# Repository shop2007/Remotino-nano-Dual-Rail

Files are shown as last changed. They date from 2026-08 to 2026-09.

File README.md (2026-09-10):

# Remotino Nano Dual Rail

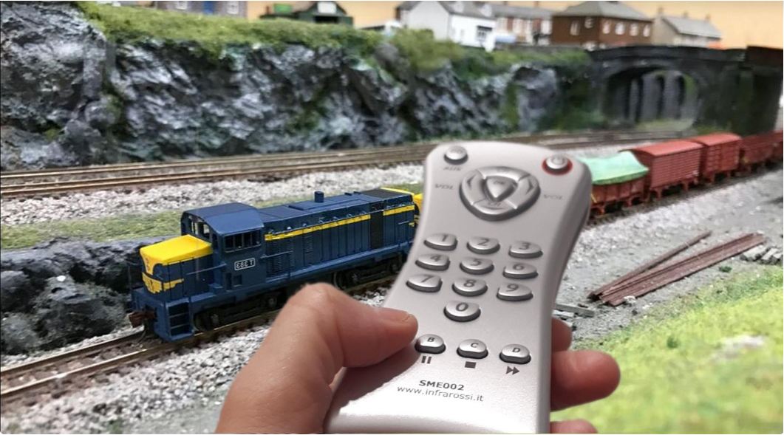
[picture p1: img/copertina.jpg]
Copertina


**Remotino Nano Dual Rail** è l'evoluzione naturale di **Remotino Nano**: un sistema completo per il controllo di un plastico ferroviario, basato su **Arduino Nano**, telecomando a infrarossi e controllo PWM dei due binari.

L'obiettivo del progetto è ottenere un controllo semplice ma preciso dei treni analogici, mantenendo allo stesso tempo la possibilità di gestire scambi, luci e altre utenze del plastico.

---

## 1. Caratteristiche principali

### 1.1 Controllo dei treni

- Controllo di un plastico con **trenini analogici** (tipo LIMA) tramite telecomando a infrarossi.
- **Due binari indipendenti**, controllati in PWM sia per la velocità sia per la direzione.
- Il controllo PWM consente velocità molto basse, realmente in scala, con **partenze e fermate lente e graduali**, più simili al comportamento di un treno reale.

### 1.1.1 Video della bassa velocità
https://github.com/user-attachments/assets/d638dfb1-e052-454d-9ad7-9dd413f32621

### 1.1.2 Video della bassa velocità
<video src="https://github.com/user-attachments/assets/59c75386-90f1-46fd-8587-ddf0c4f8ac02" controls="controls" style="max-width: 100%;"></video>

### 1.2 Gestione di scambi e utenze

- Controllo di **8 relè** per l'attivazione di:
  - scambi;
  - luci;
  - alimentazione di tronchini morti;
  - altre utenze del plastico.
- Se i relè vengono utilizzati per gli scambi in modalità monostabile, sono necessari **2 relè per ogni scambio**.
- Il sistema è espandibile verso schede da **8 o 16 relè con protocollo I²C**.

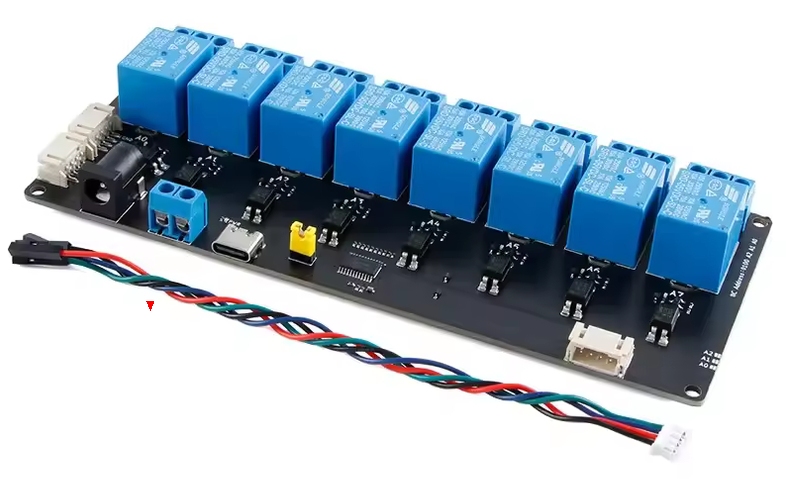
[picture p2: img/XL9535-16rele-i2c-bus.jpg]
Scheda 16 relè con bus I2C


### 1.3 Funzioni speciali

- Possibilità di unire temporaneamente i due circuiti per permettere il passaggio di un treno da un binario all'altro tramite la funzione **JOIN**.
- Funzione **BOOST** per aiutare la partenza di un treno quando viaggia a velocità molto bassa, in salita o con un carico elevato.
- Regolazione fine del comportamento dinamico tramite **5 potenziometri/trimmer**.
- Protezione dei circuiti tramite **quattro fusibili PTC autoripristinanti**.

---

## 2. Mappa comandi del telecomando

Tutte le funzioni del sistema vengono gestite tramite i tasti del telecomando a infrarossi:

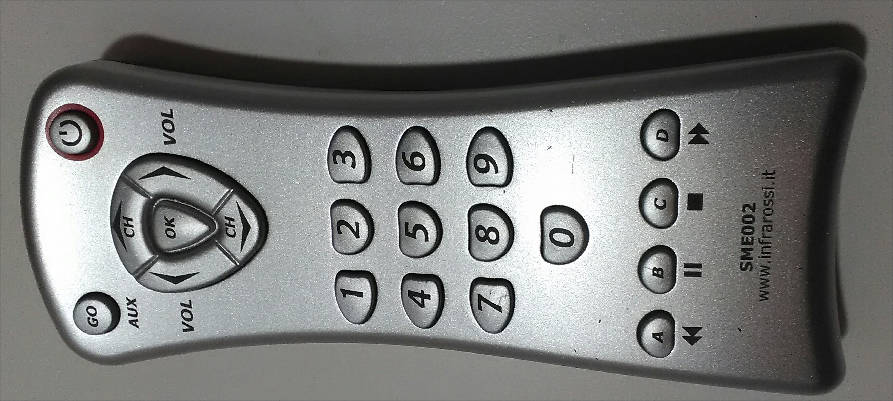
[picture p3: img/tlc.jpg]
Telecomando usato


| Tasto | Funzione / Azione |
| :--- | :--- |
| **GO** | Attiva i motori (*primo tasto da premere per avviare i treni*). |
| **POWER ON** | Ferma immediatamente tutti i treni (Arresto d'emergenza). |
| **CH UP** | Se la potenza è 0 seleziona marcia avanti su **Binario 1** e/o aumenta progressivamente la velocità. Se era selezionata la marcia indietro, riduce la velocità fino ad invertire in marcia avanti. |
| **CH DOWN** | Se la potenza è 0 seleziona marcia indietro su **Binario 1** e/o aumenta progressivamente la velocità. Se era selezionata la marcia avanti, riduce la velocità fino ad invertire in marcia indietro. |
| **VOL +** | Identico a `CH UP`, ma per il **Binario 2**. |
| **VOL -** | Identico a `CH DOWN`, ma per il **Binario 2**. |
| **OK** *(Tasto centrale)* | **Boost** alla massima velocità per il binario selezionato (entrambi se la funzione `JOIN` è attiva). |
| **0** | Porta lentamente la velocità a 0 per il binario selezionato (entrambi se la funzione `JOIN` è attiva). |
| **9** | Attiva la modalità **JOIN** (unione temporanea dei due binari). Si disattiva con **0**|
| **1 – 8** | Aziona il rispettivo relè (da 1 a 8) del banco selezionato, in base alla modalità impostata (chiude temporaneamente in monostabile o inverte lo stato in bistabile). |
| **A** | Seleziona il **Banco 1** di 8 relè (imposta `MODO_A` alla configurazione/reset). |
| **B** | Seleziona il **Banco 2** di 8 relè (imposta `MODO_B` alla configurazione/reset). |
| **C** | Seleziona il **Banco 3** di 8 relè (imposta `MODO_C` alla configurazione/reset). |
| **D** | Seleziona il **Banco 4** di 8 relè (imposta `MODO_D` alla configurazione/reset). |

---

## 3. Architettura del sistema

Il progetto è organizzato attorno ad Arduino Nano, che gestisce:

- i due circuiti di alimentazione dei binari;
- la regolazione PWM della velocità;
- il comando della direzione;
- la funzione JOIN;
- gli 8 relè;
- la ricezione dei comandi dal telecomando;
- la lettura dei potenziometri per la calibrazione della risposta dinamica;
- la comunicazione seriale con il PC.

Per la realizzazione pratica vengono utilizzati, dove possibile, **moduli e schede commerciali**. Lo schema generale riportato più avanti è quindi utile per comprendere l'architettura, mentre per una replica completa del progetto bisogna fare riferimento allo **schema reale KiCad** contenuto nella cartella `kicad`.

---

## 4. Configurazione degli 8 relè

Gli 8 relè possono essere configurati in **quattro modalità**, in funzione dell'utilizzo previsto sul plastico.

| Modalità | Configurazione |
|---|---|
| **MODO_A** | 8 relè monostabili per 4 scambi. Il tasto 1 chiude il relè 1 finché resta premuto. |
| **MODO_B** | 8 relè bistabili ON/OFF per 8 attivazioni. Il tasto 1 inverte lo stato del relè 1 a ogni pressione. |
| **MODO_C** | 6 relè monostabili per 3 scambi + 2 relè bistabili ON/OFF per 2 attivazioni. |
| **MODO_D** | 4 relè monostabili per 2 scambi + 4 relè bistabili ON/OFF per 2 attivazioni. |

### Memorizzazione della modalità

La modalità viene selezionata **subito dopo il reset** premendo il relativo tasto:

- `A` → MODO_A
- `B` → MODO_B
- `C` → MODO_C
- `D` → MODO_D

La configurazione scelta viene quindi **memorizzata nella EEPROM** e mantenuta anche dopo lo spegnimento.

---

## 5. Cambio binario — funzione JOIN

La funzione **JOIN** permette di far passare un treno dal binario 1 al binario 2 evitando il collegamento diretto fra due circuiti che possono trovarsi a tensioni differenti.

### 5.1 Preparazione del collegamento

Per consentire fisicamente il passaggio del treno, i due circuiti devono essere collegati da un tratto di binario che presenti una **interruzione su entrambe le rotaie**.

Nel prototipo questa interruzione è stata realizzata con un seghetto da ferro.

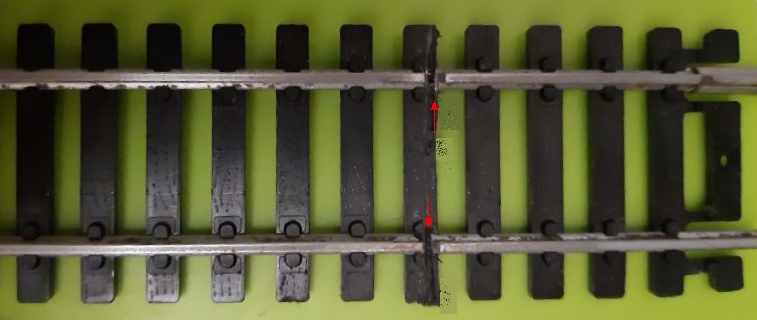
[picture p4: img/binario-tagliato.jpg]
Foto binario tagliato


Non è necessario unire elettricamente i due circuiti: è proprio la funzione JOIN che predispone Arduino a generare due tensioni identiche, permettendo il passaggio da un binario all'altro, senza problema alcuno.

### 5.2 Funzionamento

Premendo il **tasto 9**:

1. le tensioni dei due circuiti vengono portate a zero;
2. viene attivata la modalità JOIN;
3. lo stesso comando viene applicato a entrambi i circuiti;
4. il treno può attraversare il tratto di collegamento passando da un binario all'altro;
5. terminata la necessità del collegamento, il sistema può tornare al normale funzionamento indipendente.

In questo modo il passaggio avviene senza applicare direttamente al treno due tensioni differenti.

### 5.3 Protezione

Quattro **fusibili PTC autoripristinanti** proteggono i circuiti da eventuali errori.

Un esempio particolarmente importante è il tentativo di cambiare binario **senza aver prima attivato la funzione JOIN**: in questa situazione si potrebbe creare un cortocircuito fra circuiti alimentati a tensioni differenti.

---

## 6. Funzione BOOST

La funzione **BOOST** è pensata per i casi in cui il treno, viaggiando alla velocità minima, tende a fermarsi.

Premendo il tasto **OK** del telecomando:

- viene individuato l'ultimo circuito pilotato;
- se il sistema è in modalità JOIN, la funzione può interessare entrambi i circuiti;
- vengono applicati **brevi impulsi alla massima tensione**.

Il BOOST può essere utile:

- alla velocità minima;
- per superare una salita;
- quando il treno ha molti vagoni;
- quando un motore fatica a ripartire.

L'impulso ha lo scopo di **sbloccare il treno e consentirgli di riprendere il movimento**, senza dover aumentare stabilmente la velocità impostata.

---

## 7. Regolazione tramite Potenziometri / Trimmer

Sulla scheda sono presenti **5 potenziometri (o trimmer)** che consentono di personalizzare in modo preciso il comportamento dei treni e le rampe di accelerazione/frenata:

1. **Valore Boost**  
   Regola la durata/intensità dell'impulso di spunto al momento dell'avvio o alla pressione del tasto dedicato (`OK`), permettendo di superare gli attriti meccanici iniziali o i punti critici del plastico.

2. **Valore Minimum Speed**  
   Imposta il livello minimo del segnale PWM (velocità minima). Permette di definire la soglia alla quale la motrice inizia a muoversi senza ronzii o stalli del motore.

3. **Accelerazione**  
   Imposta la pendenza della rampa di accelerazione. Permette di determinare il tempo impiegato dal treno per raggiungere la velocità desiderata, simulando la tipica inerzia delle motrici reali.

4. **Decelerazione**  
   Regola la rampa di decelerazione standard durante le normali variazioni di velocità o cambi di marcia, garantendo rallentamenti morbidi e realistici.

5. **Deceleraz. fermata automatica**  
   Regola la rampa di arresto dedicata alle fermate automatiche (es. alla pressione del tasto `0` . Permette di variare la curva di decelerazione automatica fino all'arresto del treno.

---

## 8. Remotino Display

Collegando Arduino Nano a una porta USB e avviando l'eseguibile **Remotino Display**, è possibile visualizzare sul PC lo stato del sistema.

Il pannello mostra:

- stato di **MOTOR ON**;
- direzione dei due binari;
- stato della funzione **JOIN** (comando 9);
- due VU meter analogici con la potenza erogata ai due motori;
- stato dei **4 scambi**.

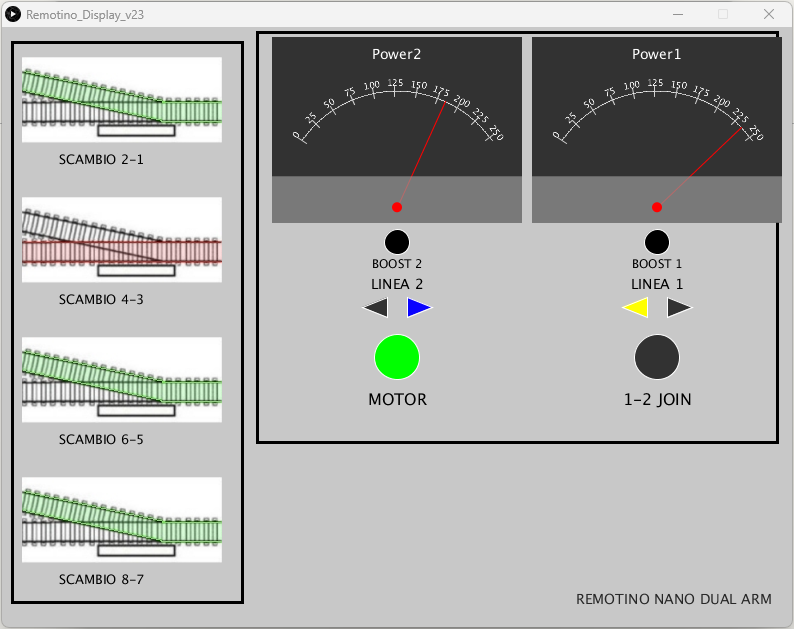
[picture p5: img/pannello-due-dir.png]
Pannello di controllo su PC


Il Remotino Display è quindi particolarmente utile per il controllo e il monitoraggio del plastico durante il funzionamento.

---

## 9. Debug e verifica dell'hardware

In caso di malfunzionamento dell'hardware è possibile utilizzare il **monitor seriale di Arduino** per comandare direttamente i relè e verificarne il funzionamento.

Il formato del comando è:

`rXY`

dove:

- `r` identifica il comando relè;
- `X` identifica il numero del relè;
- `Y` indica lo stato:
  - `1` = ON
  - `0` = OFF

### Esempi

- `r11` → attiva il relè 1
- `r20` → disattiva il relè 2

Questa funzione consente di verificare i relè indipendentemente dal normale funzionamento del telecomando e delle altre funzioni del programma.

---

## 10. Schema generale e realizzazione hardware

### 10.1 Schema generale

Lo schema seguente mostra, a titolo esemplificativo, l'architettura complessiva del sistema (mancano i 5 trimmer/pot.).

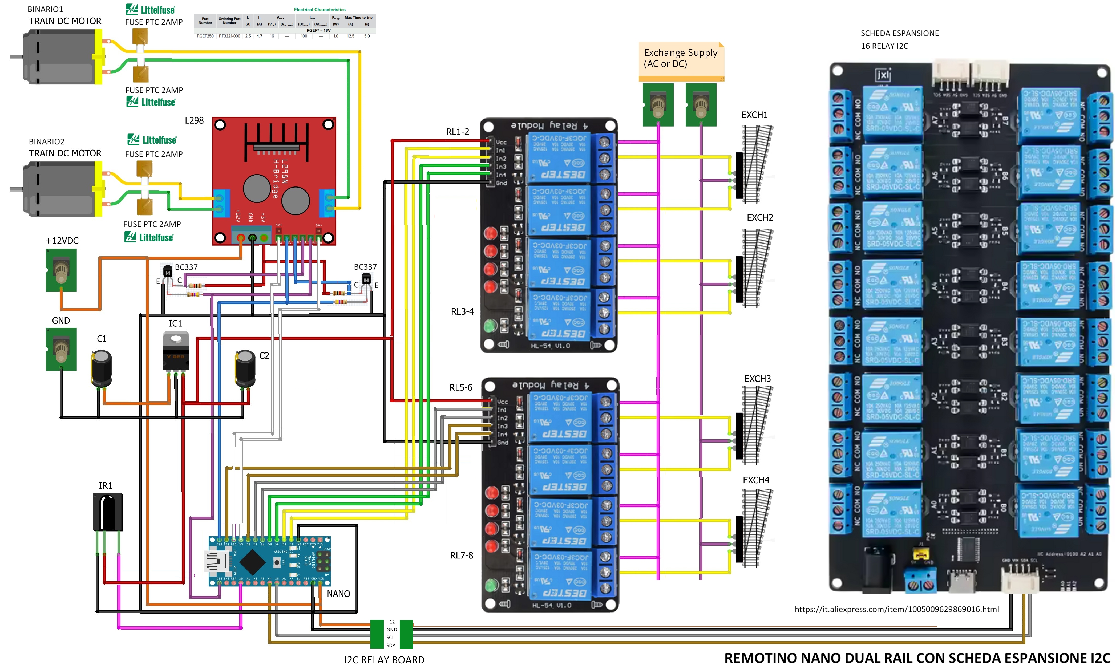
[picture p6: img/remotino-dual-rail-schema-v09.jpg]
Schemone generale


Per **replicare realmente il progetto** fa fede lo schema elettrico completo realizzato in **KiCad**, disponibile nella cartella `kicad`.

Dove possibile sono state impiegate schede e moduli commerciali, in modo da semplificare la costruzione e la reperibilità dei componenti.

### 10.2 PCB

Il PCB è in fase di sviluppo.

Se sei interessato ad averne uno, è possibile prenotarlo: viene fornito **al costo** e nudo (senza componenti).

---

## 11. Prototipo

Questa è l'immagine del primo prototipo, realizzato come verifica preliminare del progetto.

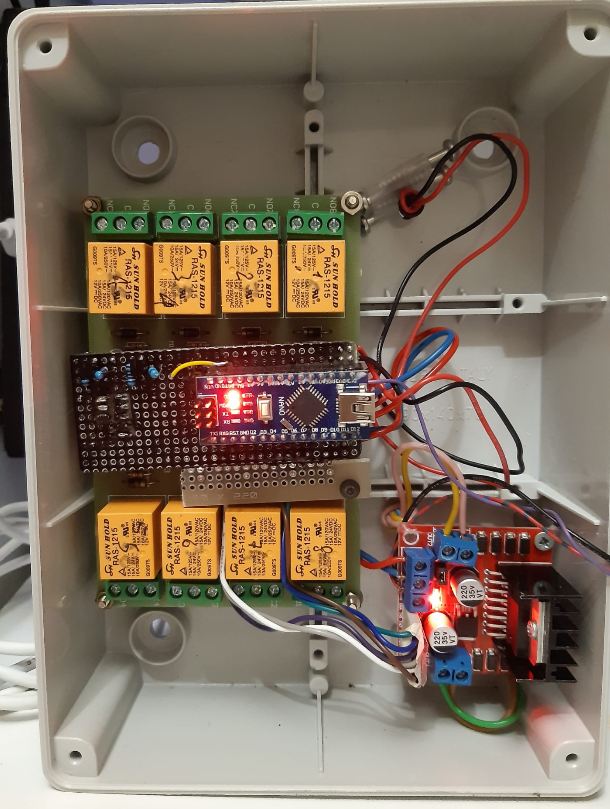
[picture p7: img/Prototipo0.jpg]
Primo prototipo


Il prototipo verrà sostituito da una costruzione più definitiva con il PCB dedicato.

---

## 12. Sorgenti OPEN SOURCE

Tutti i sorgenti del progetto sono disponibili nella cartella **`Sorgenti`**.

Sono disponibili:

- i sorgenti per **Arduino Nano**;
- i sorgenti del programma **Remotino Display**.
- gli schemi **Kicad**.

Il progetto può quindi essere studiato, modificato e adattato alle proprie esigenze.

---

## 13. Istruzioni per la realizzazione

Per chi ha meno esperienza con Arduino è disponibile una guida **passo-passo** nella cartella **`Istruzioni facili`**.

La guida è stata pensata per consentire di replicare il progetto anche a chi possiede solo una conoscenza di base di Arduino e dell'elettronica.

In caso di difficoltà durante la realizzazione, è possibile segnalare il problema per ricevere supporto ( LPAUTAS GMAIL).

---

## 14. In sintesi

**Remotino Nano Dual Rail** riunisce in un unico sistema:

- controllo indipendente di **due treni analogici**;
- regolazione PWM della velocità e della direzione;
- partenze e fermate progressive;
- regolazione personalizzabile di **accelerazione, decelerazione, stop, min speed e boost** tramite 5 trimmer;
- funzione **JOIN** per il passaggio fra i due circuiti;
- funzione **BOOST** per facilitare la partenza dei treni;
- gestione di **8 relè**, configurabili in quattro modalità;
- possibilità di espansione tramite **I²C**;
- protezione tramite PTC autoripristinanti;
- monitoraggio tramite **Remotino Display**;
- funzioni di **debug hardware**;
- sorgenti open source;
- documentazione passo-passo per la realizzazione.



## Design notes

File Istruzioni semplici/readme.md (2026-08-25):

# Checklist realizzazione — Remotino Nano Dual Rail

Guida pratica per chi parte da zero, basata sulle cartelle presenti nella repository.

## Software

1. Scarica e installa **Arduino IDE 2** dal sito ufficiale arduino.cc.
2. Apri Arduino IDE e carica lo sketch `.ino` che trovi nella cartella **"Arduino Sketch"**. Assicurati di aver installato la libreria IRremote v. 2,7,0 di Shirriff (le versioni successive non funzionano con questo progetto).
3. Prova a compilarlo (Verifica). Se l'IDE segnala una libreria mancante, installala dal **Library Manager** (icona libro a sinistra) e ricompila.
4. Collega l'Arduino Nano al PC via USB, seleziona la scheda **"Arduino Nano"** e la porta seriale corretta, poi carica lo sketch sulla scheda. Attenzione, con i cloni è necessario installare il driver USB CH341SER.EXE scaricabile dal sito ufficiale WCH (WCH-IC) .
5. Apri il monitor seriale a 115200 baud e verifica che compaiano i messaggi diagnostici (es. `PWM1=`, `MOTN=`) quando invii un comando relè via seriale (es. `r11`, `r20`).

## Hardware e schema

6. Realizza il circuito che trovi nella cartella  **"img"** per capire l'architettura complessiva del sistema (binari, relè, telecomando, alimentazione).
7. Se hai poca esperienza con Arduino ed elettronica, segui la guida passo-passo nella cartella **"Istruzioni semplici"**.
8. Per la realizzazione elettrica reale (o per farti fare il PCB), apri lo schema completo nella cartella **"Kicad"** — serve installare KiCad se vuoi visualizzarlo o modificarlo.
9. Realizza il cablaggio seguendo lo schema KiCad: alimentazione, i due circuiti binario, le schede relè, i 4 fusibili PTC.
10. Inserisci l'Arduino Nano nello zoccolo/basetta predisposta.
11. Se vuoi usare la funzione **JOIN**, taglia con un seghetto entrambe le rotaie nel punto di collegamento tra binario 1 e binario 2 (senza unirle elettricamente).

## Primo avvio e collaudo

12. Alimenta il sistema e, con il monitor seriale aperto, verifica lo stato generale prima di collegare il telecomando.
13. Alla prima accensione (o dopo un reset), premi subito **A / B / C / D** per scegliere la modalità dei relè (Banco 1‑4: monostabili per scambi, bistabili per luci, o combinazioni miste) — la scelta va fatta entro i primi tasti premuti, poi resta salvata in EEPROM.
14. Prova i comandi da telecomando: premi **GO** per abilitare i motori (nessun treno si muove prima), poi **CH+/CH−** per il binario 1 e **VOL+/VOL−** per il binario 2.
15. Prova **OK** per il boost e **0** per fermare dolcemente il binario selezionato; verifica **POWER ON** come arresto d'emergenza di tutto.
16. Se hai realizzato il taglio del binario, prova la funzione **JOIN** con il tasto **9** e verifica il passaggio del treno tra i due binari, poi disattivala con **0**.
17. Prova i tasti **1–8** per verificare l'attivazione dei relè nella modalità scelta.

## Remotino Display (opzionale ma consigliato)

18. Installa Processing usando il link nella cartella **"Processing installer"** )versioni più aggiornate non compilano il sorgente).
19. Apri lo sketch .pde dentro **"Processing sketch"** e avvialo con l'Arduino collegato via USB, per visualizzare il pannello di stato (Motor On, direzione, JOIN, VU meter di potenza, stato dei 4 scambi). Opzionalmente puoi provare direttamente il file .exe che trovi nella cartella **"Processing sketch\application.windows64"** .. non sempre funziona.

## Se qualcosa non funziona

20. Usa il monitor seriale per comandare i relè manualmente (`rXY`, es. `r11` accende il relè 1, `r20` spegne il relè 2) e isolare se il problema è hardware o software.

## Appendice: elenco parti

- Telecomando: Wallis Universal SME002 (trovato su ebay, vinted) - E' possibile usare qualsiasi telecomando ma serve modificare lo sketch con i codici corretti, e si rischia di ricevere disturbi da telecomandi tv, vcr ecc
- Testina IR: vanno tutte bene, ma consiglio la LTM-8848 LITEON perchè è schermata ed ha una elevata sensibilità (trovata su ebay, vinted)
- Arduino NANO (originale o clone)
- Scheda 4 relè (2 pezzi) ( https://it.aliexpress.com/item/1005008364256415.html )
- Scheda opzionale 8/16 relè I2C bus ( https://it.aliexpress.com/item/1005009629869016.html )
- Scheda PWM L298 ( https://it.aliexpress.com/item/1005012997846403.html )
- BC337
- Resistori e trimmer vari
- Connettori vari
- Fusibili PTC da 2 amp (Littelfuse RUE110 oppure Bourns MF-R110)
- PCB Remotino Nano Dual Rail (in preparazione, prenota il tuo)

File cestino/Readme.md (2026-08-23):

# Remotino Nano Dual Rail

Copertina

**Remotino Nano Dual Rail** è l'evoluzione naturale di **Remotino Nano**: un sistema completo per il controllo di un plastico ferroviario in scala H0, basato su **Arduino Nano**, telecomando a infrarossi e controllo PWM dei due binari.

L'obiettivo del progetto è ottenere un controllo semplice ma preciso dei treni analogici, mantenendo allo stesso tempo la possibilità di gestire scambi, luci e altre utenze del plastico.

---

## 1. Caratteristiche principali

### 1.1 Controllo dei treni

- Controllo di un plastico con **trenini analogici** (tipo LIMA) tramite telecomando a infrarossi.

Telecomando usato

- **Due binari indipendenti**, controllati in PWM sia per la velocità sia per la direzione.
- Il controllo PWM consente velocità molto basse, realmente in scala 1:87, con **partenze e fermate lente e graduali**, più simili al comportamento di un treno reale.

https://github.com/user-attachments/assets/d638dfb1-e052-454d-9ad7-9dd413f32621

### 1.2 Gestione di scambi e utenze

- Controllo di **8 relè** per l'attivazione di:
  - scambi;
  - luci;
  - alimentazione di tronchini morti;
  - altre utenze del plastico.
- Se i relè vengono utilizzati per gli scambi in modalità monostabile, sono necessari **2 relè per ogni scambio**.
- Il sistema è espandibile verso schede da **8 o 16 relè con protocollo I²C**.

Scheda 16 relè con bus I2C

### 1.3 Funzioni speciali

- Possibilità di unire temporaneamente i due circuiti per permettere il passaggio di un treno da un binario all'altro tramite la funzione **JOIN**.
- Funzione **BOOST** per aiutare la partenza di un treno quando viaggia a velocità molto bassa, in salita o con un carico elevato.
- Protezione dei circuiti tramite **quattro fusibili PTC autoripristinanti**.

---

## 2. Architettura del sistema

Il progetto è organizzato attorno ad Arduino Nano, che gestisce:

- i due circuiti di alimentazione dei binari;
- la regolazione PWM della velocità;
- il comando della direzione;
- la funzione JOIN;
- gli 8 relè;
- la ricezione dei comandi dal telecomando;
- la comunicazione seriale con il PC.

Per la realizzazione pratica vengono utilizzati, dove possibile, **moduli e schede commerciali**. Lo schema generale riportato più avanti è quindi utile per comprendere l'architettura, mentre per una replica completa del progetto bisogna fare riferimento allo **schema reale KiCad** contenuto nella cartella `kicad`.

---

## 3. Configurazione degli 8 relè

Gli 8 relè possono essere configurati in **quattro modalità**, in funzione dell'utilizzo previsto sul plastico.

| Modalità | Configurazione |
|---|---|
| **MODO_A** | 8 relè monostabili per 4 scambi. Il tasto 1 chiude il relè 1 finché resta premuto. |
| **MODO_B** | 8 relè bistabili ON/OFF per 8 attivazioni. Il tasto 1 inverte lo stato del relè 1 a ogni pressione. |
| **MODO_C** | 6 relè monostabili per 3 scambi + 2 relè bistabili ON/OFF per 2 attivazioni. |
| **MODO_D** | 4 relè monostabili per 2 scambi + 4 relè bistabili ON/OFF per 2 attivazioni. |

### Memorizzazione della modalità

<<<<<<< HEAD
La modalità viene selezionata **subito dopo il reset** premendo il relativo tasto:
=======
Per passare dal binario 1 al binario 2 è necessario che i due circuiti siano uniti da un binario con una interruzione su entramble le rotaie (io l'ho fatto con un segheto da ferro); per il passaggio non serve unirle elettricamente, perché attivando la modalità "join" con il tasto 9, le tensioni dei due circuiti vengono prima azzerate e poi viene applicato lo stesso comando su entrambi i circuiti, permettendo al treno di passare da un binario all'altro in modo del tutto indolore.
Foto binario tagliato
>>>>>>> 6fffbd93348ce626d40769e0fa216ff54d8fa7e9

- `A` → MODO_A
- `B` → MODO_B
- `C` → MODO_C
- `D` → MODO_D

La configurazione scelta viene quindi **memorizzata nella EEPROM** e mantenuta anche dopo lo spegnimento.

---

## 4. Cambio binario — funzione JOIN

La funzione **JOIN** permette di far passare un treno dal binario 1 al binario 2 evitando il collegamento diretto fra due circuiti che possono trovarsi a tensioni differenti.

### 4.1 Preparazione del collegamento

Per consentire fisicamente il passaggio del treno, i due circuiti devono essere collegati da un tratto di binario che presenti una **interruzione su entrambe le rotaie**.

Nel prototipo questa interruzione è stata realizzata con un seghetto da ferro.

Foto binario tagliato

Non è necessario unire elettricamente i due circuiti: è proprio la funzione JOIN a gestire temporaneamente le loro tensioni.

### 4.2 Funzionamento

Premendo il **tasto 9**:

1. le tensioni dei due circuiti vengono portate a zero;
2. viene attivata la modalità JOIN;
3. lo stesso comando viene applicato a entrambi i circuiti;
4. il treno può attraversare il tratto di collegamento passando da un binario all'altro;
5. terminata la necessità del collegamento, il sistema può tornare al normale funzionamento indipendente.

In questo modo il passaggio avviene senza applicare direttamente al treno due tensioni differenti.

### 4.3 Protezione

Quattro **fusibili PTC autoripristinanti** proteggono i circuiti da eventuali errori.

Un esempio particolarmente importante è il tentativo di cambiare binario **senza aver prima attivato la funzione JOIN**: in questa situazione si potrebbe creare un cortocircuito fra circuiti alimentati a tensioni differenti.

---

## 5. Funzione BOOST

La funzione **BOOST** è pensata per i casi in cui il treno, viaggiando alla velocità minima, tende a fermarsi.

Premendo il tasto **OK** del telecomando:

- viene individuato l'ultimo circuito pilotato;
- se il sistema è in modalità JOIN, la funzione può interessare entrambi i circuiti;
- vengono applicati **brevi impulsi alla massima tensione**.

Il BOOST può essere utile:

- alla velocità minima;
- per superare una salita;
- quando il treno ha molti vagoni;
- quando un motore fatica a ripartire.

L'impulso ha lo scopo di **sbloccare il treno e consentirgli di riprendere il movimento**, senza dover aumentare stabilmente la velocità impostata.

---

## 6. Remotino Display

Collegando Arduino Nano a una porta USB e avviando l'eseguibile **Remotino Display**, è possibile visualizzare sul PC lo stato del sistema.

Il pannello mostra:

- stato di **MOTOR ON**;
- direzione dei due binari;
- stato della funzione **JOIN** (comando 9);
- due VU meter analogici con la potenza erogata ai due motori;
- stato dei **4 scambi**.

Pannello di controllo su PC

Il Remotino Display è quindi particolarmente utile per il controllo e il monitoraggio del plastico durante il funzionamento.

---

## 7. Debug e verifica dell'hardware

In caso di malfunzionamento dell'hardware è possibile utilizzare il **monitor seriale di Arduino** per comandare direttamente i relè e verificarne il funzionamento.

Il formato del comando è:

`rXY`

dove:

- `r` identifica il comando relè;
- `X` identifica il numero del relè;
- `Y` indica lo stato:
  - `1` = ON
  - `0` = OFF

### Esempi

- `r11` → attiva il relè 1
- `r20` → disattiva il relè 2

Questa funzione consente di verificare i relè indipendentemente dal normale funzionamento del telecomando e delle altre funzioni del programma.

---

## 8. Schema generale e realizzazione hardware

### 8.1 Schema generale

Lo schema seguente mostra, a titolo esemplificativo, l'architettura complessiva del sistema.

Schemone generale

Per **replicare realmente il progetto** fa fede lo schema elettrico completo realizzato in **KiCad**, disponibile nella cartella `kicad`.

Dove possibile sono state impiegate schede e moduli commerciali, in modo da semplificare la costruzione e la reperibilità dei componenti.

### 8.2 PCB

Il PCB è in fase di costruzione.

Se sei interessato a realizzarne uno, è possibile prenotarlo: viene fornito **al costo**.

---

## 9. Prototipo

Questa è l'immagine del primo prototipo, realizzato come verifica preliminare del progetto.

Primo prototipo

Il prototipo verrà sostituito da una costruzione più definitiva con il PCB dedicato.

---

## 10. Sorgenti OPEN SOURCE

Tutti i sorgenti del progetto sono disponibili nella cartella **`Sorgenti`**.

Sono disponibili:

- i sorgenti per **Arduino Nano**;
- i sorgenti del programma **Remotino Display**.

Il progetto può quindi essere studiato, modificato e adattato alle proprie esigenze.

---

## 11. Istruzioni per la realizzazione

Per chi ha meno esperienza con Arduino è disponibile una guida **passo-passo** nella cartella **`Istruzioni facili`**.

La guida è stata pensata per consentire di replicare il progetto anche a chi possiede solo una conoscenza di base di Arduino e dell'elettronica.

In caso di difficoltà durante la realizzazione, è possibile segnalare il problema per ricevere supporto.

---

## 12. In sintesi

**Remotino Nano Dual Rail** riunisce in un unico sistema:

- controllo indipendente di **due treni analogici**;
- regolazione PWM della velocità e della direzione;
- partenze e fermate progressive;
- funzione **JOIN** per il passaggio fra i due circuiti;
- funzione **BOOST** per facilitare la partenza dei treni;
- gestione di **8 relè**, configurabili in quattro modalità;
- possibilità di espansione tramite **I²C**;
- protezione tramite PTC autoripristinanti;
- monitoraggio tramite **Remotino Display**;
- funzioni di **debug hardware**;
- sorgenti open source;
- documentazione passo-passo per la realizzazione.

<<<<<<< HEAD
=======
## Prototipo
Questa è l'immagine del primi prototipo, in attesa di una costruzione più seria quando ci sarà il pcb.
Prototipo 0

## versioni

# Remotino Nano Dual Rail

Copertina

**Remotino Nano Dual Rail** è l'evoluzione naturale di **Remotino Nano**: un sistema completo per il controllo di un plastico ferroviario in scala H0, basato su **Arduino Nano**, telecomando a infrarossi e controllo PWM dei due binari.

L'obiettivo del progetto è ottenere un controllo semplice ma preciso dei treni analogici, mantenendo allo stesso tempo la possibilità di gestire scambi, luci e altre utenze del plastico.

---

## 1. Caratteristiche principali

### 1.1 Controllo dei treni

- Controllo di un plastico con **trenini analogici** (tipo LIMA) tramite telecomando a infrarossi.

Telecomando usato

- **Due binari indipendenti**, controllati in PWM sia per la velocità sia per la direzione.
- Il controllo PWM consente velocità molto basse, realmente in scala 1:87, con **partenze e fermate lente e graduali**, più simili al comportamento di un treno reale.

https://github.com/user-attachments/assets/d638dfb1-e052-454d-9ad7-9dd413f32621

### 1.2 Gestione di scambi e utenze

- Controllo di **8 relè** per l'attivazione di:
  - scambi;
  - luci;
  - alimentazione di tronchini morti;
  - altre utenze del plastico.
- Se i relè vengono utilizzati per gli scambi in modalità monostabile, sono necessari **2 relè per ogni scambio**.
- Il sistema è espandibile verso schede da **8 o 16 relè con protocollo I²C**.

Scheda 16 relè con bus I2C

### 1.3 Funzioni speciali

- Possibilità di unire temporaneamente i due circuiti per permettere il passaggio di un treno da un binario all'altro tramite la funzione **JOIN**.
- Funzione **BOOST** per aiutare la partenza di un treno quando viaggia a velocità molto bassa, in salita o con un carico elevato.
- Protezione dei circuiti tramite **quattro fusibili PTC autoripristinanti**.

---

## 2. Architettura del sistema

Il progetto è organizzato attorno ad Arduino Nano, che gestisce:

- i due circuiti di alimentazione dei binari;
- la regolazione PWM della velocità;
- il comando della direzione;
- la funzione JOIN;
- gli 8 relè;
- la ricezione dei comandi dal telecomando;
- la comunicazione seriale con il PC.

Per la realizzazione pratica vengono utilizzati, dove possibile, **moduli e schede commerciali**. Lo schema generale riportato più avanti è quindi utile per comprendere l'architettura, mentre per una replica completa del progetto bisogna fare riferimento allo **schema reale KiCad** contenuto nella cartella `kicad`.

---

## 3. Configurazione degli 8 relè

Gli 8 relè possono essere configurati in **quattro modalità**, in funzione dell'utilizzo previsto sul plastico.

| Modalità | Configurazione |
|---|---|
| **MODO_A** | 8 relè monostabili per 4 scambi. Il tasto 1 chiude il relè 1 finché resta premuto. |
| **MODO_B** | 8 relè bistabili ON/OFF per 8 attivazioni. Il tasto 1 inverte lo stato del relè 1 a ogni pressione. |
| **MODO_C** | 6 relè monostabili per 3 scambi + 2 relè bistabili ON/OFF per 2 attivazioni. |
| **MODO_D** | 4 relè monostabili per 2 scambi + 4 relè bistabili ON/OFF per 2 attivazioni. |

### Memorizzazione della modalità

La modalità viene selezionata **subito dopo il reset** premendo il relativo tasto:

- `A` → MODO_A
- `B` → MODO_B
- `C` → MODO_C
- `D` → MODO_D

La configurazione scelta viene quindi **memorizzata nella EEPROM** e mantenuta anche dopo lo spegnimento.

---

## 4. Cambio binario — funzione JOIN

La funzione **JOIN** permette di far passare un treno dal binario 1 al binario 2 evitando il collegamento diretto fra due circuiti che possono trovarsi a tensioni differenti.

### 4.1 Preparazione del collegamento

Per consentire fisicamente il passaggio del treno, i due circuiti devono essere collegati da un tratto di binario che presenti una **interruzione su entrambe le rotaie**.

Nel prototipo questa interruzione è stata realizzata con un seghetto da ferro.

Foto binario tagliato

Non è necessario unire elettricamente i due circuiti: è proprio la funzione JOIN a gestire temporaneamente le loro tensioni.

### 4.2 Funzionamento

Premendo il **tasto 9**:

1. le tensioni dei due circuiti vengono portate a zero;
2. viene attivata la modalità JOIN;
3. lo stesso comando viene applicato a entrambi i circuiti;
4. il treno può attraversare il tratto di collegamento passando da un binario all'altro;
5. terminata la necessità del collegamento, il sistema può tornare al normale funzionamento indipendente.

In questo modo il passaggio avviene senza applicare direttamente al treno due tensioni differenti.

### 4.3 Protezione

Quattro **fusibili PTC autoripristinanti** proteggono i circuiti da eventuali errori.

Un esempio particolarmente importante è il tentativo di cambiare binario **senza aver prima attivato la funzione JOIN**: in questa situazione si potrebbe creare un cortocircuito fra circuiti alimentati a tensioni differenti.

---

## 5. Funzione BOOST

La funzione **BOOST** è pensata per i casi in cui il treno, viaggiando alla velocità minima, tende a fermarsi.

Premendo il tasto **OK** del telecomando:

- viene individuato l'ultimo circuito pilotato;
- se il sistema è in modalità JOIN, la funzione può interessare entrambi i circuiti;
- vengono applicati **brevi impulsi alla massima tensione**.

Il BOOST può essere utile:

- alla velocità minima;
- per superare una salita;
- quando il treno ha molti vagoni;
- quando un motore fatica a ripartire.

L'impulso ha lo scopo di **sbloccare il treno e consentirgli di riprendere il movimento**, senza dover aumentare stabilmente la velocità impostata.

---

## 6. Remotino Display

Collegando Arduino Nano a una porta USB e avviando l'eseguibile **Remotino Display**, è possibile visualizzare sul PC lo stato del sistema.

Il pannello mostra:

- stato di **MOTOR ON**;
- direzione dei due binari;
- stato della funzione **JOIN** (comando 9);
- due VU meter analogici con la potenza erogata ai due motori;
- stato dei **4 scambi**.

Pannello di controllo su PC

Il Remotino Display è quindi particolarmente utile per il controllo e il monitoraggio del plastico durante il funzionamento.

---

## 7. Debug e verifica dell'hardware

In caso di malfunzionamento dell'hardware è possibile utilizzare il **monitor seriale di Arduino** per comandare direttamente i relè e verificarne il funzionamento.

Il formato del comando è:

`rXY`

dove:

- `r` identifica il comando relè;
- `X` identifica il numero del relè;
- `Y` indica lo stato:
  - `1` = ON
  - `0` = OFF

### Esempi

- `r11` → attiva il relè 1
- `r20` → disattiva il relè 2

Questa funzione consente di verificare i relè indipendentemente dal normale funzionamento del telecomando e delle altre funzioni del programma.

---

## 8. Schema generale e realizzazione hardware

### 8.1 Schema generale

Lo schema seguente mostra, a titolo esemplificativo, l'architettura complessiva del sistema.

Schemone generale

Per **replicare realmente il progetto** fa fede lo schema elettrico completo realizzato in **KiCad**, disponibile nella cartella `kicad`.

Dove possibile sono state impiegate schede e moduli commerciali, in modo da semplificare la costruzione e la reperibilità dei componenti.

### 8.2 PCB

Il PCB è in fase di costruzione.

Se sei interessato a realizzarne uno, è possibile prenotarlo: viene fornito **al costo**.

---

## 9. Prototipo

Questa è l'immagine del primo prototipo, realizzato come verifica preliminare del progetto.

Primo prototipo

Il prototipo verrà sostituito da una costruzione più definitiva con il PCB dedicato.

---

## 10. Sorgenti OPEN SOURCE

Tutti i sorgenti del progetto sono disponibili nella cartella **`Sorgenti`**.

Sono disponibili:

- i sorgenti per **Arduino Nano**;
- i sorgenti del programma **Remotino Display**.

Il progetto può quindi essere studiato, modificato e adattato alle proprie esigenze.

---

## 11. Istruzioni per la realizzazione

Per chi ha meno esperienza con Arduino è disponibile una guida **passo-passo** nella cartella **`Istruzioni facili`**.

La guida è stata pensata per consentire di replicare il progetto anche a chi possiede solo una conoscenza di base di Arduino e dell'elettronica.

In caso di difficoltà durante la realizzazione, è possibile segnalare il problema per ricevere supporto.

---

## 12. In sintesi

**Remotino Nano Dual Rail** riunisce in un unico sistema:

- controllo indipendente di **due treni analogici**;
- regolazione PWM della velocità e della direzione;
- partenze e fermate progressive;
- funzione **JOIN** per il passaggio fra i due circuiti;
- funzione **BOOST** per facilitare la partenza dei treni;
- gestione di **8 relè**, configurabili in quattro modalità;
- possibilità di espansione tramite **I²C**;
- protezione tramite PTC autoripristinanti;
- monitoraggio tramite **Remotino Display**;
- funzioni di **debug hardware**;
- sorgenti open source;
- documentazione passo-passo per la realizzazione.

>>>>>>> 6fffbd93348ce626d40769e0fa216ff54d8fa7e9

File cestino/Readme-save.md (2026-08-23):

# Remotino Nano Dual Rail

Copertina

**Remotino Nano Dual Rail** è l'evoluzione naturale di Remotino Nano.

## Caratteristiche principali

- Controllo totale di un plastico con Trenini analogici (tipo LIMA), tramite telecomando a infrarossi

Telecomando usato
  
- Due binari indipendenti, controllati in PWM sia per velocità che per direzione
- Il controllo PWM consente velocità bassissime, realmente in scala 1:87, con partenze e fermate lente e graduali, proprio come un treno vero
 
https://github.com/user-attachments/assets/d638dfb1-e052-454d-9ad7-9dd413f32621

- Possibilità di unire temporaneamente i due circuiti per far passare un treno da un binario all'altro (funzione speciale join tasto 9)
- Controllo di 8 relè per l'attivazione di scambi, luci o alimentazione di tronchini morti. Se usati per gli scambi, in modalità monostabile servono 2 relè per ogni scambio
- Espandibilità verso schede da 8/16 relais con protocollo I2C

Scheda 16 Relè IC bus Aliexp

## Modalità di configurazione degli 8 relè

Gli 8 relè possono essere configurati in 4 modalità:

| Modalità | Configurazione |
|---|---|
| **MODO_A** | 8 relè monostabili per 4 scambi (il tasto 1 chiude il relè 1 finché resta premuto) |
| **MODO_B** | 8 relè bistabili ON/OFF per 8 attivazioni (il tasto 1 inverte lo stato del relè 1 ad ogni pressione) |
| **MODO_C** | 6 relè monostabili per 3 scambi + 2 relè bistabili ON/OFF per 2 attivazioni |
| **MODO_D** | 4 relè monostabili per 2 scambi + 4 relè bistabili ON/OFF per 2 attivazioni |
Questa programmazione va fatta premendo i tasti A,B,C o D appena resettato, poi resta memorizzato nella EEPROM

## Cambio binario (funzione JOIN)

Per passare dal binario 1 al binario 2 è necessario che i due circuiti siano uniti da un binario con una interruzione su entramble le rotaie (io l'ho fatto con un seghetto da ferro); per il passaggio non serve unirle elettricamente, perché attivando la modalità "join" con il tasto 9, le tensioni dei due circuiti vengono prima azzerate e poi viene applicato lo stesso comando su entrambi i circuiti, permettendo al treno di passare da un binario all'altro in modo del tutto indolore.
Foto binario tagliato

Quattro fusibili PTC autoripristinanti proteggono i circuiti da eventuali errori, come ad esempio il tentativo di cambiare binario senza aver prima premuto il tasto 9 — situazione che provocherebbe un cortocircuito tra le diverse tensioni.

## Remotino Display

Collegando Arduino Nano a una porta USB e lanciando l'eseguibile **Remotino Display**, è possibile visualizzare:

- Stato di motor on
- Direzione dei due binari
- Stato di JOIN (comando 9)
- Due VU meter analogici con la potenza erogata ai due motori
- Stato dei 4 scambi
Pannello di controllo su PC

## Debug hardware

In caso di malfunzionamento dell'hardware è possibile inviare alcuni comandi da monitor seriale per attivare i relais e verificarne il funzionamento 

-  r=relay , 1=rl1, 1=on 0=off
- r11 attiva rele1
- r20 disattiva rele 2

## Schema Generale per replicare il progetto
Solo a titolo esemplificativo questo è lo schemone totale del controllo. Dove possibile vengono impegate schede o moduli commerciali. Per replicare il progetto fa fede lo schema reale, fatto in kicad (cartella kicad).
Il PCB è in fase di costruzione, se sei interessato prenotane uno (viene dato "al costo").
Schemone generale

## Tasto BOOST
Sul telecomando premendo il tasto OK si attiva la funzione BOOST: all'ultimo circuito pilotato (o entrambi se siamo in modo JOIN) vengono dati brevi impulsi alla massima tensione: serve per quando abbiamo la velocità al minimo, ed il treno si ferma , o per una salita, o per problemi di carico elevato (numero di vagoni); questo dovrebbe sbloccare il treno e consentirgli di proseguire.

## Sorgenti OPEN SOURCE
Tutti i sorgenti per Arduino Nano e quelli per il "Remotino Display" sono open source disponibili nella cartella "Sorgenti".

## Istruzioni facili per i meno esperti
Ho scritto una istruzione fatta passo-per-passo, che dovrebbe consentire di replicare il progetto a chiunque abbia un minimo di dimestichezza con Arduino. Scrivimi se incontri difficoltà. Cerca la cartella "Istruzioni facili".

## Prototipo
Questa è l'immagine del primi prototipo, in attesa di una costruzione più seria quando ci sarà il pcb.
Prototipo 0

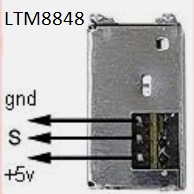
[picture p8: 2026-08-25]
img/LTM8848-PINOUT.jpg

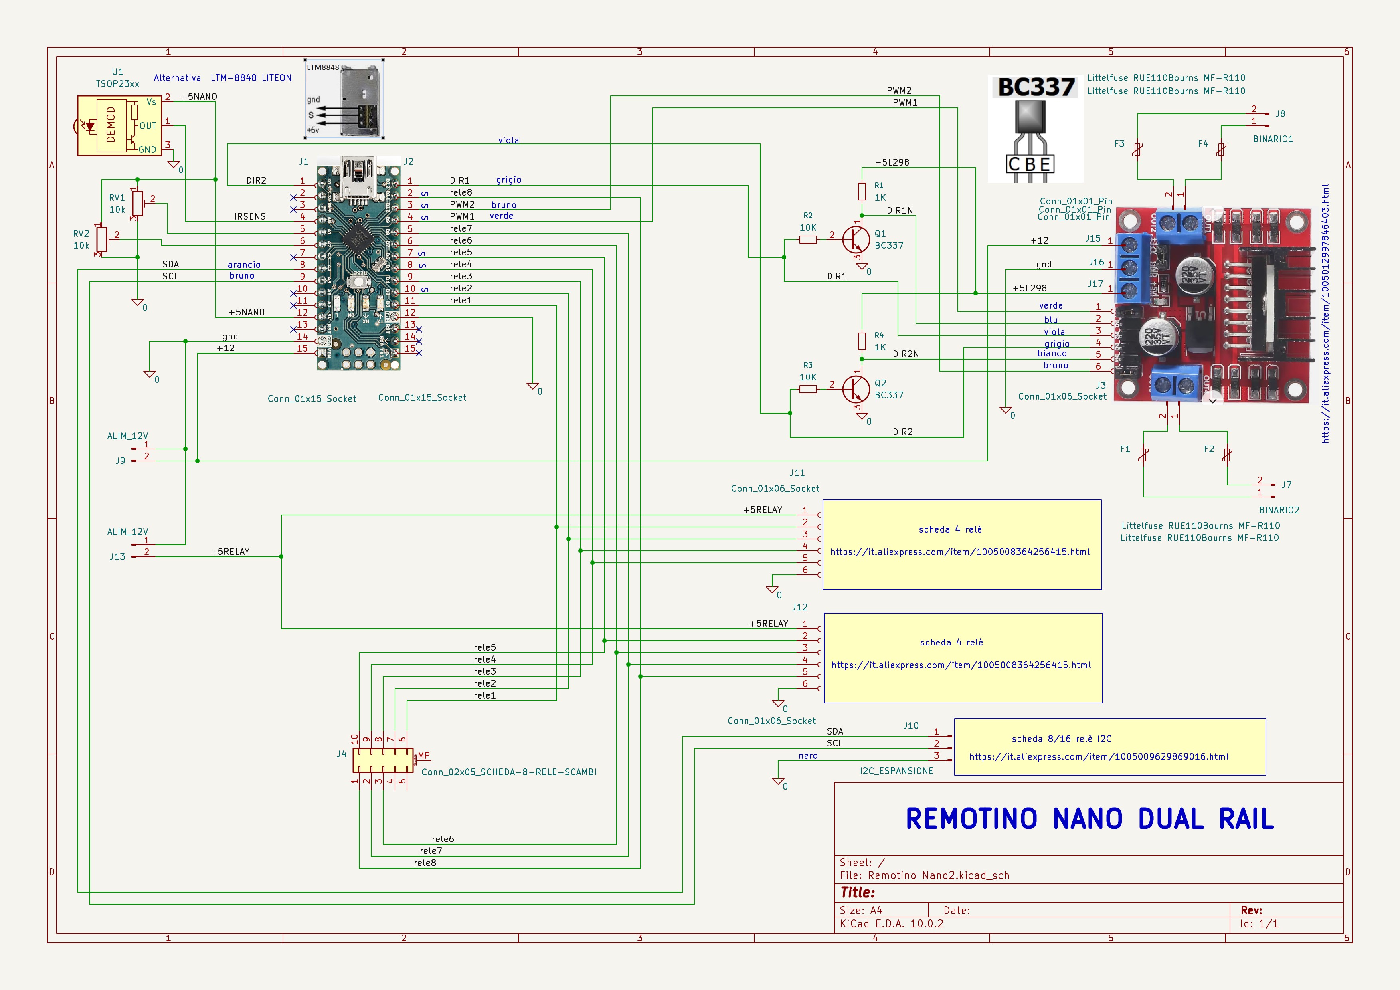
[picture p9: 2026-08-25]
Kicad/Remotino Nano Dual Rail/Schematic Remotino Nano Dual Rail v2.0.jpg

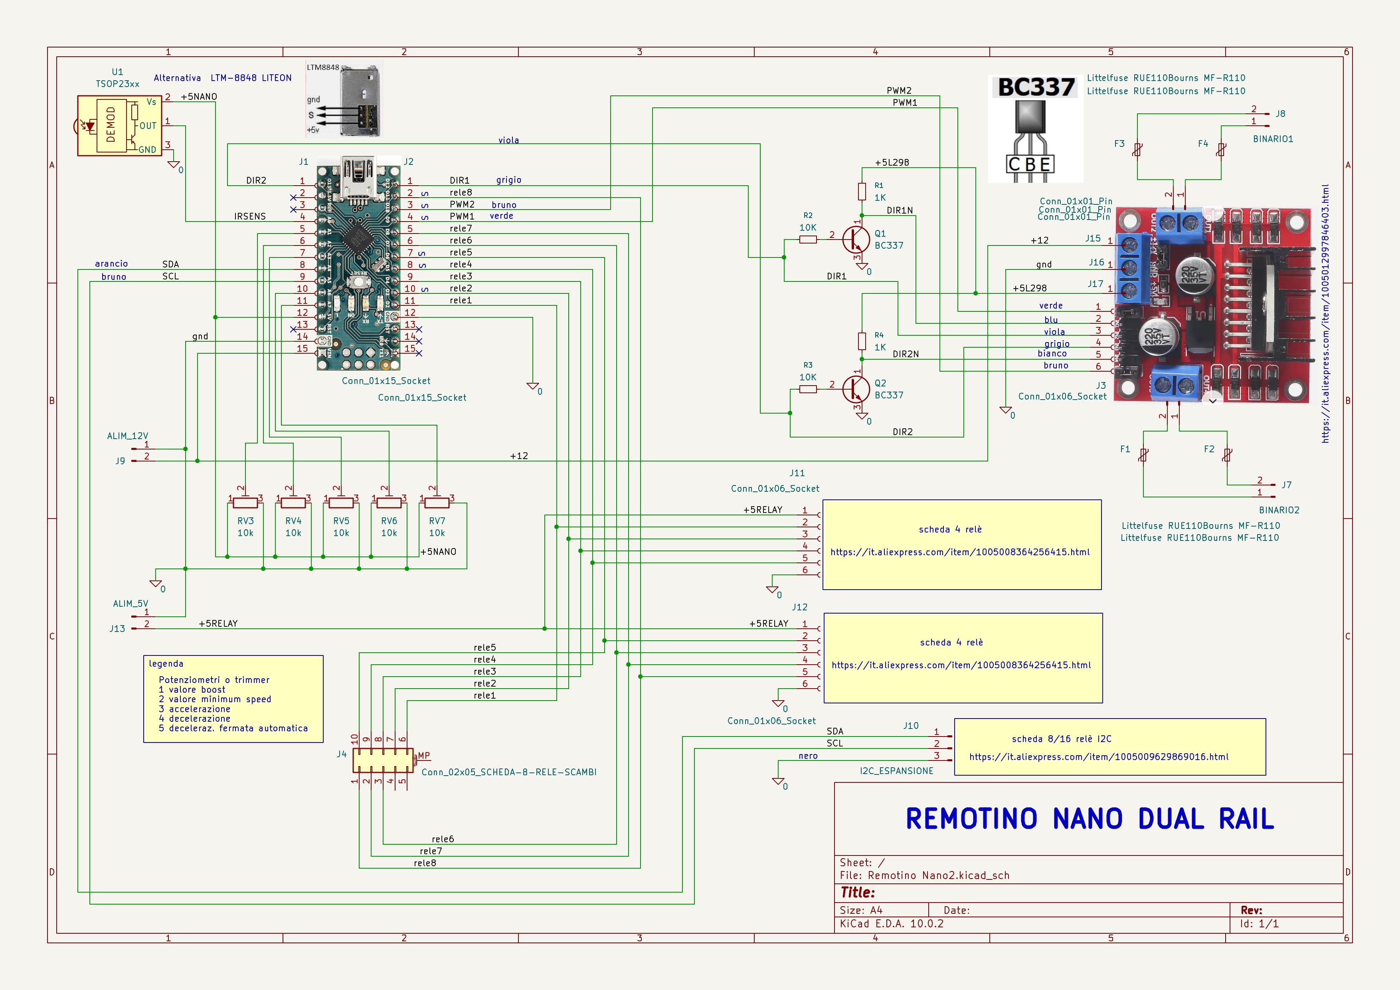
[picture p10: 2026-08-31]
Kicad/Remotino Nano Dual Rail/Schematic Remotino Nano Dual Rail v3.0.jpg

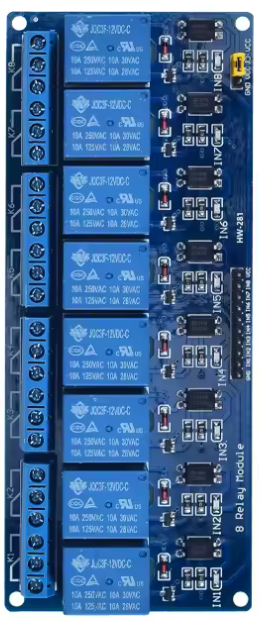
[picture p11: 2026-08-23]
img/1005007003070916 Modulo relè ottico.png

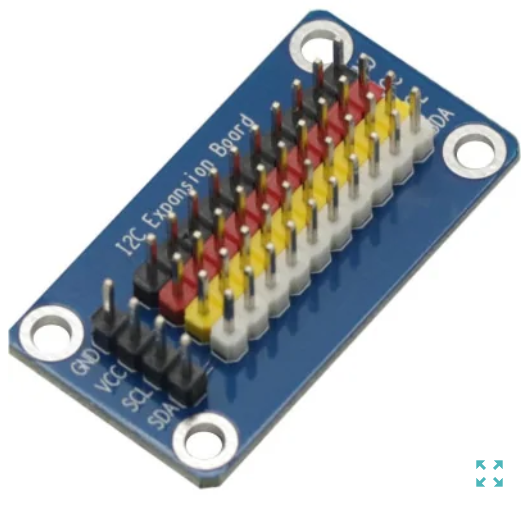
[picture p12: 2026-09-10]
img/Board_parallelatore_I2C.png

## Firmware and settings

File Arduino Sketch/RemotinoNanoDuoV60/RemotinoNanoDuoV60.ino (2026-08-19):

/*
  
  modifiche
  
  v60 pwm passato da 900hx a 8khz
  v52 pin direzione 1 e 2 erano invertiti
  v50 rigistro circolare tasti premuti
  v40 cambio da analogwrite a scrittura PWM dei registri OCR
  
  sketch by Pautasso Luciano, Turin Italy  lpautas@gmail.com
  compila con irremote dalla 1.0 alla 2.7
  la 2.8 da errore


  comandi seriali
  
  r=relay , 1=rl1, 1=on 0=off
  r11 attiva rele1
  r20 disattiva rele 2



 

*/


//Remote Control SME002 Wallis Universal key table

#define key_0     0x700 //imposta velocita binario (1 o 2) a 0
#define key_1     0x701
#define key_2     0x702
#define key_3     0x703
#define key_4     0x704
#define key_5     0x705
#define key_6     0x706
#define key_7     0x707
#define key_8     0x708
#define key_9     0x709

#define key_a     0x72b //imposta velocita binario (1 o 2) a 100
#define key_b     0x72c //imposta velocita binario (1 o 2) a 150
#define key_c     0x72d //imposta velocita binario (1 o 2) a 200
#define key_d     0x72e //imposta velocita binario (1 o 2) a 255

#define key_go    0x738
#define key_off   0x70C
#define key_chp   0x720 //increm vel bin 1 e sel bin 1
#define key_chm   0x721 //decrem vel bin 1 e sel bin 1
#define key_volp  0x710 //increm vel bin 2 e sel bin 2
#define key_volm  0x711 //decrem vel bin 2 e sel bin 2
#define key_ok    0x717 //boost





#define BOARD_NANO
//#define BOARD_KA05   //estensione relè diversa dal default




//xxxxxxxxxxxxxxxxxxxxxxxxxxxxxxxxxxxxxxxxxxxxxxxxxxxxxxxxxxxxxxxxxxxx
//
// TIPO DI TELECOMANDO

#define TLC_SME002
//xxxxxxxxxxxxxxxxxxxxxxxxxxxxxxxxxxxxxxxxxxxxxxxxxxxxxxxxxxxxxxxxxxxx





#include <IRremote.h>

#include <EEPROM.h>
//indirizzi EEProm
int EEPROMaddr = 10; // 10 = Mode





/*
#ifdef BOARD_NANO
int RECV_PIN = 10; // UNO input IR pin  11
#endif
*/

#ifdef BOARD_KA05
  int RECV_PIN = 7; // UNO input IR pin  7 su ka05
#else
  int RECV_PIN = A0; // UNO input IR pin  10
#endif


//nota funziona solo se sotto lo stesso timer
#define PWM1_PIN 9
#define PWM1_PIN 10




IRrecv irrecv(RECV_PIN);

decode_results results;

String inputString = "";         // a string to hold incoming data
boolean stringComplete = false;  // whether the string is complete

int UltimaMarcia = 0;  // vale 0, 25, 50, 75, 100   , 0 = no marce
int CodeReceived;
int KeyPressed = 255;
int TempToggle;
int Togglelast = 0;
bool ProtocolOK;
char Mode = 'a' ; // vale "a" "b" "c" "d", letto da eeprom, decide modalità di funzionamento
bool Debug = false;
bool DebugMillis = false ;
bool FlagKeyPressed = false;
bool FlagFirstRun = true;
bool ChangeModeInProgress = false;
unsigned long TimeLastKeyPressed;
unsigned long TimeBlink;
int Temp;
bool CodiceIrValido = false ; // Si mette true quando un codice IR è ricevuto

bool SingleMode = false; //


#ifdef BOARD_KA05
  int Pin_PWM_Mot1 = 6; //  canale pwm1
#else
  int Pin_PWM_Mot1 = 10; //  canale pwm1    
  int Pin_PWM_Mot2 = 9; //  canale pwm1  
#endif


unsigned char PWM1 = 0; // Valore attuale della PWM del motore1
unsigned char PWM2 = 0; // Valore attuale della PWM del motore2
bool DIREZIONE1 = true; // Direzione attuale Motore 1 False indietro, Trua Avanti
bool DIREZIONE2 = true; // Direzione attuale Motore 2 False indietro, Trua Avanti
bool MOTORON = false; // Stato del motor on

/*

  //accelerazione veloce
  unsigned char Accelera = 20; // incremento di velocità
  unsigned char Rallenta = 20; // decremeto per rallenta
  unsigned char Fermata = 10; // decremento per
*/
unsigned char Accelera = 5; // incremento di velocità
unsigned char Rallenta = 5; // decremeto per rallenta
unsigned char Fermata = 3; // decremento per


int ContaIR = 0; // si conta ogni IR valido ricevuto e solo entro i primi 5 è possibile cambiare modo
bool ModeCambiabile = true; // dopo due ir ricevuti diventa false


int ContaFrames = 0;
unsigned long  Debug1 = 0;
unsigned long  Debug2 = 0;
unsigned long  Debug3 = 0;

//xxxxxxxxxxxxxxxxxxxxxxxxxxxxxxxxxxxxxxxxxxxxxxxxxxxxxxxxxxxxxxxxxxxxxxxxxx
#define KEYBUF_SIZE 16
int KeyBuf[KEYBUF_SIZE];
volatile uint8_t KeyBufHead = 0;
volatile uint8_t KeyBufTail = 0;

void PushKey(int code) {
    uint8_t next = (KeyBufHead + 1) % KEYBUF_SIZE;
    if (next != KeyBufTail) {   // evita overflow
        KeyBuf[KeyBufHead] = code;
        KeyBufHead = next;
    }
}

bool PopKey(int *code) {
    if (KeyBufTail == KeyBufHead) return false; // buffer vuoto
    *code = KeyBuf[KeyBufTail];
    KeyBufTail = (KeyBufTail + 1) % KEYBUF_SIZE;
    return true;
}











int UltimoBinarioComandato = 0; //vale 1 o 2




#ifdef BOARD_KA05
  #define NumeroRele 7  //6+1
#else
  #define NumeroRele 8  //8+1
#endif

#ifdef BOARD_NANO
// #define NumeroRele 8
//#define NumeroRele 9
#endif





int TimeOut = 140; 

bool ReleStatus[NumeroRele]; // ARRAY, Contiene lo stato del relè, True = Chiuso, False = Aperto

bool ReleType[NumeroRele];  // ARRAY, Contiene il tipo del relè, True = Bistabile , False = Monostabile

int RelePin[NumeroRele];   // ARRAY, Contiene i pin relativi ai vari relè

bool ReleToggle[NumeroRele];   // ARRAY, Contiene il prossimo stato del relè che è oggetto di toggle


//PROTOTIPI
const char* getSourceFileName(void);
void printSourceFileName(void);
void setup(void);
void PrintStatus3(void);
void AggiornaStatoRele(void);
void OpenAllRele(void);
void PreProcessaTasto(void);
void ProcessaComandoSeriale(void);
void ChangeMode(int NewMode);
void PrintStatus(void);
void DisAttivaRele(int KeyPressed);
void AttivaRele(int KeyPressed);
void ImpostaVelocita(int VelMax);
void ImpostaVelocitaBinario(int VelMax);
void ProcessaTasto(int FuCodeReceived);
void ChangeMode2(char NewMode);
void dump(decode_results *results);
bool CheckCodiceIr(void);
void loop(void);
void AggiornaStatoMotori(void);
void GoMotorOn(void);
void Pwm1Up(void);
void Pwm1Down(void);
void Pwm2Up(void);
void Pwm2Down(void);
void Boost130(void);
void EmergencyStop(void);
void serialEvent(void);


//*******************************************************************
/*
bool diagnosticsFunctionTraceEnabled = false;
class FunctionTraceScope {
public:
  explicit FunctionTraceScope(const char* functionName)
      : functionName(functionName), active(diagnosticsFunctionTraceEnabled) {
    if (!active) return;
    Serial.print('#');
    Serial.print(functionName);
    Serial.println(" Start");
  }

  ~FunctionTraceScope() {
    if (!active) return;
    Serial.print('#');
    Serial.print(functionName);
    Serial.println("End");
  }

private:
  const char* functionName;
  bool active;
};

#define TRACE_BLOCKING_FUNCTION() FunctionTraceScope _functionTrace(__FUNCTION__)
*/
const char* getSourceFileName() {
  const char* path = __FILE__;
  const char* base = path;

  while (*path != '\0') {
    if (*path == '/' || *path == '\\') {
      base = path + 1;
    }
    path++;
  }

  static char fileName[96];
  size_t len = strlen(base);

  if (len > 4 && strcmp(base + len - 4, ".cpp") == 0) {
    len -= 4;
  }

  if (len >= sizeof(fileName)) {
    len = sizeof(fileName) - 1;
  }

  memcpy(fileName, base, len);
  fileName[len] = '\0';
  return fileName;
}

void printSourceFileName() {
  Serial.print("File .ino: ");
  Serial.println(getSourceFileName());
}


//**************************************************************************************

//Dichiarazione di funzione che punta all'indirizzo zero
void(* Riavvia)(void) = 0;

void setup()
{
  //XXXXXXXXXXXXXXXXXXXXXXXXXXXXXXXXXXXXXXXXXXXXXXXXXXXXXXXX
// inizializza timer1 per avere uscire fasate e sincronizzate per poterle mettere in parallelo
// Arduino Nano / ATmega328P
// D9  = OC1A
// D10 = OC1B

  pinMode(9, OUTPUT);
  pinMode(10, OUTPUT);

  //-----------------------------------------------------------------

    // Timer1: Fast PWM 8 bit, modalità 5
    // Frequenza ≈ 490 Hz con clock 16 MHz e prescaler 64
    TCCR1A = 0;
    TCCR1B = 0;

    TCCR1A |= (1 << COM1A1) | (1 << COM1B1); // PWM su D9 e D10
    TCCR1A |= (1 << WGM10);                  // Fast PWM 8 bit
    TCCR1B |= (1 << WGM12);


  //#define pwm490Hz
  #define pwm4KHz
  //-----------------------------------------------------------------    
  #ifdef pwm490Hz
    TCCR1B |= (1 << CS11) | (1 << CS10);     // prescaler 64
  #endif
  //-----------------------------------------------------------------
  #ifdef pwm4KHz
    TCCR1B |= (1 << CS11);     // Prescaler = 8
  #endif
  //-----------------------------------------------------------------

  // Stesso duty-cycle per entrambe le uscite
  OCR1A = 1; //quasi 0
  OCR1B = 1;
  //XXXXXXXXXXXXXXXXXXXXXXXXXXXXXXXXXXXXXXXXXXXXXXXXXXXXXXXX
  // COLLEGA I RELE AI PIN



#ifdef BOARD_KA05
  
#else
  
#endif

#ifdef BOARD_KA05
  #define RELE1 8
  #define RELE2 9
  #define RELE3 10
  #define RELE4 11
  #define RELE5 12
  #define RELE6 13

  RelePin[0] = RELE1;
  RelePin[1] = RELE2;
  RelePin[2] = RELE3;
  RelePin[3] = RELE4;
  RelePin[4] = RELE5;
  RelePin[5] = RELE6; 

#else
  /*
  #define RELE1 2
  #define RELE2 3
  #define RELE3 4
  #define RELE4 5
  #define RELE5 6
  #define RELE6 7
  #define RELE7 8
  #define RELE8 11

  */
  #define RELE1 7
  #define RELE2 8
  #define RELE3 11
  #define RELE4 2
  #define RELE5 3
  #define RELE6 4
  #define RELE7 5
  #define RELE8 6





  RelePin[0] = RELE1;
  RelePin[1] = RELE2;
  RelePin[2] = RELE3;
  RelePin[3] = RELE4;
  RelePin[4] = RELE5;
  RelePin[5] = RELE6;
  RelePin[6] = RELE7;
  RelePin[7] = RELE8;

#endif










  //riempie gli array
  for (int indice = 0; indice < (NumeroRele); indice++)
  {
    ReleStatus[indice] = true; //true bistabili toggle
    ReleType[indice] = true; // tutti bistabili toggle
    ReleToggle[indice] = false; //decide se attiva o disattiva al keypress, invertito dal loop al timeout
  }





  //XXXXXXXXXXXXXXXXXXXXXXXXXXXXXXXXXXXXXXXXXXXXXXXXXXX
  // IMPOSTA I BIT RELE COME OUTPUT

#ifdef BOARD_KA05
  
#else
  
#endif



#ifdef BOARD_KA05
  pinMode(RELE1, OUTPUT);
  pinMode(RELE2, OUTPUT);
  pinMode(RELE3, OUTPUT);
  pinMode(RELE4, OUTPUT);
  pinMode(RELE5, OUTPUT);
  pinMode(RELE6, OUTPUT);

  // IMPOSTA I BIT MOTORI COME OUTPUT
  #define MOT1_DIREZIONE 4
  #define MOT2_DIREZIONE 5
  
#else
  pinMode(RELE1, OUTPUT);
  pinMode(RELE2, OUTPUT);
  pinMode(RELE3, OUTPUT);
  pinMode(RELE4, OUTPUT);
  pinMode(RELE5, OUTPUT);
  pinMode(RELE6, OUTPUT);
  pinMode(RELE7, OUTPUT);
  pinMode(RELE8, OUTPUT);

  // IMPOSTA I BIT MOTORI COME OUTPUT
  #define MOT1_DIREZIONE 13
  #define MOT2_DIREZIONE 12
  
#endif

  pinMode(MOT1_DIREZIONE, OUTPUT);
  pinMode(MOT2_DIREZIONE, OUTPUT);







  Serial.begin(115200);

  // reserve 200 bytes for the inputString:
  inputString.reserve(200);

  irrecv.enableIRIn(); // Start the receiver


  EEPROMaddr = 10; // 10 = Mode
  Mode = EEPROM.read(EEPROMaddr);

// Just to know which program is running on my Arduino
    //Serial.println(F("START " __FILE__ " from " __DATE__ "\r\nUsing library version " VERSION_IRREMOTE));
    //Serial.print(F("library version ")); Serial.println(VERSION_IRREMOTE);


  printSourceFileName();
  //Serial.println(F("RemotinoNanoV20_irA0_p1 "));

  Serial.print(F("Modehex "));
  Serial.println(Mode, HEX);

  #define ReleBistabile true
  #define ReleMonostabile false 
  
  // cambia il mode scrivendo nell'array i valori
  switch (Mode) {
    case 'b': 
      //  Modo B , 8 bistabili ON/OFF , ogni volta inverte lo stato
      for (int indice = 0; indice < (NumeroRele); indice++)
      {
        ReleType[indice] = ReleBistabile; // tutti bistabili toggle
      }
      break;

    case 'c':    //
      // Modo C -   
      for (int indice = 0; indice < (NumeroRele); indice++)
      {
        ReleType[indice] = ReleMonostabile; 
      }
      ReleType[0] = ReleBistabile;
      ReleType[1] = ReleBistabile;
      break;

    case 'd':    //
      // Modo D - RELE 1,2,3,4 BISTABILI, RELE' 5 6 7 8 MONOSTABILI SCAMBIO
      for (int indice = 0; indice < (NumeroRele); indice++)
      {
        ReleType[indice] = ReleMonostabile; 
      }
      
      for (int indice = 0; indice < (4); indice++)
      {
        ReleType[indice] = ReleBistabile; 
      }





      //questi di seguito i monostabili, lascia solo 1 e 2 bistabili


#ifdef BOARD_NANO
#endif


      break;

    default:
      // Modo A , 8 rele monostabili, 140msec , ReleMonostabile false   
      for (int indice = 0; indice < (NumeroRele); indice++)
      {
        ReleType[indice] = ReleMonostabile; //false  monostabili
      }
      TimeOut = 140;
  }


  delay(500);

  if (( Mode < 'a' ) || ( Mode > 'd' )) {
    Serial.println(F("PASS-E2?"));
    delay(200);


    while (Serial.available() == 0) {
    }


    if (Serial.read() == 'p') {
      EEPROMaddr = 10; // 10 = Mode
      EEPROM.write(EEPROMaddr, 'a');
    }
    else  {
      Serial.println(F("Reset!!"));
      delay(1000);
      Riavvia();
    }


  }


#ifdef BOARD_NANO
  Serial.println(F("Board NANO"));
#endif







  PrintStatus();

  //AggiornaStatoRele();
  OpenAllRele();

}
//xxxxxxxxxxxxxxxxxxxxxxxxxxxxxxxxxxxxxxxxxxxxxxxxxxxxxxxxxxxxxxxxxxx
void PrintStatus3() {




  Serial.print(F("ARRAY 01234567 -> ReleType "));
  for (int indice = 0; indice < (NumeroRele); indice++)
  {
    if (ReleType[indice] == true) {
      Serial.print(F("1"));
    } else {
      Serial.print(F("0"));
    }
  }

  Serial.print(F("   ReleToggle "));
  for (int indice = 0; indice < (NumeroRele); indice++)
  {
    if (ReleToggle[indice] == true) {
      Serial.print(F("1"));
    } else {
      Serial.print(F("0"));
    }
  }

  Serial.print(F("   ReleStatus "));
  for (int indice = 0; indice < (NumeroRele); indice++)
  {
    if (ReleStatus[indice] == true) {
      Serial.print(F("1"));
    } else {
      Serial.print(F("0"));
    }
  }

  Serial.println(F(" "));
  Serial.print(F("Pinout RelePin "));
  for (int indice = 0; indice < (NumeroRele); indice++)
  {
    Serial.print(indice);
    Serial.print(F(":r"));
    Serial.print(RelePin[indice]);
    Serial.print(F(", "));
  }

  AggiornaStatoMotori();


}
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
void loop() {

  if (DebugMillis)
  {
    if (Debug3 > 0)
    {
      Serial.print(F(" dbg1 "));
      Serial.println(Debug1);
      Serial.print(F(" dbg2 "));
      Serial.println(Debug2);
      Serial.print(F(" dbg3 "));
      Serial.println(Debug3);
      Debug1 = 0;
      Debug2 = 0;
      Debug3 = 0;
    }
  }


  // print the string when a newline arrives:
  if (stringComplete) {
    // Serial.println(inputString);
    ProcessaComandoSeriale();
    // clear the string:
    inputString = "";
    stringComplete = false;
    AggiornaStatoMotori();
  }

  if (FlagKeyPressed) {  //FlagKeyPressed == true


    if (DebugMillis)
    {
      Serial.println(millis());
      Serial.print(F(" dbg1 "));
      Serial.println(Debug1);
      Serial.print(F(" dbg2 "));
      Serial.println(Debug2);
      Serial.print(F(" dbg3 "));
      Serial.println(Debug3);
    }


    //------------- blinka built led per segnalare live
    if ( TimeBlink < millis() ) {
      TimeBlink = millis();
    }



    if ( millis() > TimeLastKeyPressed )
    { //      - IF ( (Millis + TimeoutB) > TimeLastKeyPressed )
      Debug3 = millis();
      FlagKeyPressed = false;

      //Serial.println("#A ");

      if (ReleType[KeyPressed] == true) //true bistabile toggle
      {
        //Serial.println("#B ");

        // ReleType  true =   bistabile
        if (ReleToggle[KeyPressed] == true)
        {
          //Serial.println("#C ");
          ReleToggle[KeyPressed] = false;
        }
        else
        {
          //Serial.println("#D ");
          ReleToggle[KeyPressed] = true;
        }
      }
      else
      {
        //ReleType false = MONOSTABILE
        DisAttivaRele(KeyPressed);
        //Serial.println("#E ");

      }
    }
  }



// ricezione IR
CheckCodiceIr();   // ora NON chiama più ProcessaTasto()

// esecuzione dei tasti in coda
int code;
if (PopKey(&code)) {
    ProcessaTasto(code);
}



}




//xxxxxxxxxxxxxxxxxxxxxxxxxxxxxxxxxxxxxxxxxxxxxxxxxxxxxxxxxxxxx
void AggiornaStatoMotori() {
  //si inizia stampando gli stati

  if (DIREZIONE1) {
    digitalWrite(MOT1_DIREZIONE, HIGH);
    //digitalWrite(MOT2_DIREZIONE, LOW);
  }
  else {
    digitalWrite(MOT1_DIREZIONE, LOW);
    //digitalWrite(MOT2_DIREZIONE, HIGH);
  }





  if (DIREZIONE2) {
    //digitalWrite(MOT1_DIREZIONE, HIGH);
    digitalWrite(MOT2_DIREZIONE, LOW);
  }
  else {
    //digitalWrite(MOT1_DIREZIONE, LOW);
    digitalWrite(MOT2_DIREZIONE, HIGH);
  }



  //AGGIORNA I PWM
  if (SingleMode){
    //usa lo stesso duty per 1 e 2
    //analogWrite(Pin_PWM_Mot1, PWM1);
    OCR1A = PWM1;
    //analogWrite(Pin_PWM_Mot2, PWM2);
    OCR1B = PWM1;
    PWM2=PWM1; // solo per la stampa di debug
  } else{
    //analogWrite(Pin_PWM_Mot1, PWM1);
    OCR1A = PWM1;
    //analogWrite(Pin_PWM_Mot2, PWM2);
    OCR1B = PWM2;
  }





  Serial.println(F(" "));
  Serial.print(F("PWM1="));
  Serial.println(PWM1);

  Serial.print(F("DIR1="));
  Serial.println(DIREZIONE1);

  if (SingleMode){
    DIREZIONE2=DIREZIONE1;
  } else {
    
  }

  Serial.print(F("PWM2="));
  Serial.println(PWM2);

  Serial.print(F("DIR2="));
  Serial.println(DIREZIONE2);

  Serial.print(F("MOTN="));
  Serial.println(MOTORON);

  Serial.print(F("SMOD="));
  if (SingleMode){
    Serial.println(F("1"));
  } else {
    Serial.println(F("0"));
  }

}


//xxxxxxxxxxxxxxxxxxxxxxxxxxxxxxxxxxxxxxxxxxxxxxxxxxxxxxxxxxxxx




//ricevuto codice GO o seriale M5
void GoMotorOn() {

  // SOLO SE è IN MOTOR OFF SI ESEGUE
  if (MOTORON == false) {
    PWM1 = 0;
    Serial.println(F( "!!! PWM1 = 0"));
    delay(100);
    MOTORON = true;
  }


}

// * * * * *

//ricevuto codice ^ o seriale M8 che aumenta velocità di PWM1 e DIREZIONE1 a true
void Pwm1Up() {

  if (MOTORON) {
    //se pwm1 è 0 regola la direzione
    if ( PWM1 == 0 ) {
      DIREZIONE1 = true;
    }

    if (DIREZIONE1) {
      //siamo già nella direzione giusta
      // controlla se PWM ha ancora capienza per sommare Accelera e non dare il giro oltre 255
      if ( (PWM1 + Accelera) > 255   ) {
        // da il giro, satura a 255
        PWM1 = 255;
      }
      else {
        //non da il giro, si somma
        PWM1 = PWM1 + Accelera;
      }

    }
    else {
      //siamo nella direzione sbagliata
      // controlla se PWM puo ancora essere decrementato di Accelera e non dare il giro sotto lo 0
      if ( (PWM1 - Accelera) <  1  ) {
        // da il giro, si satura a 0 e si inverte la direzione
        PWM1 = 0;
        Serial.println(F( "!!! PWM1 = 0"));
        DIREZIONE1 = true;
      }
      else {
        // non da il giro, si sottrae
        PWM1 = PWM1 - Accelera;
      }


    } // DIREZIONE1 == false

  } //)MOTORON)

}


//ricevuto codice v o seriale M2 che diminuisce e inverte velocità di PWM1 e DIREZIONE1 a false
void Pwm1Down() {

  if (MOTORON) {
    //se pwm1 è 0 regola la direzione
    if ( PWM1 == 0 ) {
      DIREZIONE1 = false;
    }

    if (DIREZIONE1 == false) {
      //siamo già nella direzione giusta
      // controlla se PWM ha ancora capienza per sommare Accelera e non dare il giro oltre 255
      if ( (PWM1 + Accelera) > 255   ) {
        // da il giro, satura a 255
        PWM1 = 255;
      }
      else {
        //non da il giro, si somma
        PWM1 = PWM1 + Accelera;
      }

    }
    else {
      //siamo nella direzione sbagliata
      // controlla se PWM puo ancora essere decrementato di Accelera e non dare il giro sotto lo 0
      if ( (PWM1 - Accelera) <  1  ) {
        // da il giro, si satura a 0 e si inverte la direzione
        PWM1 = 0;
        Serial.println(F( "!!! PWM1 = 0"));
        DIREZIONE1 = true;
      }
      else {
        // non da il giro, si sottrae
        PWM1 = PWM1 - Accelera;
      }


    } // DIREZIONE1 == false

  } //)MOTORON)

}


//xxxxxxxxxxxxxxxxxxxxxxxxxxxxxxxxxxxxxxxxxxxxxxxxxxxxxxxxxxxxx


void Pwm2Up() {


  if (MOTORON) {
    //se pwm1 è 0 regola la direzione
    if ( PWM2 == 0 ) {
      DIREZIONE2 = true;
    }

    if (DIREZIONE2) {
      //siamo già nella direzione giusta
      // controlla se PWM ha ancora capienza per sommare Accelera e non dare il giro oltre 255
      if ( (PWM2 + Accelera) > 255   ) {
        // da il giro, satura a 255
        PWM2 = 255;
      }
      else {
        //non da il giro, si somma
        PWM2 = PWM2 + Accelera;
      }

    }
    else {
      //siamo nella direzione sbagliata
      // controlla se PWM puo ancora essere decrementato di Accelera e non dare il giro sotto lo 0
      if ( (PWM2 - Accelera) <  1  ) {
        // da il giro, si satura a 0 e si inverte la direzione
        PWM2 = 0;
        Serial.println(F( "!!! PWM2 = 0"));
        DIREZIONE2 = true;
      }
      else {
        // non da il giro, si sottrae
        PWM2 = PWM2 - Accelera;
      }


    } // DIREZIONE1 == false

  } //)MOTORON)



}

//xxxxxxxxxxxxxxxxxxxxxxxxxxxxxxxxxxxxxxxxxxxxxxxxxxxxxxxxxxxxx


void Pwm2Down() {


  if (MOTORON) {
    //se pwm1 è 0 regola la direzione
    if ( PWM2 == 0 ) {
      DIREZIONE2 = false;
    }

    if (DIREZIONE2 == false) {
      //siamo già nella direzione giusta
      // controlla se PWM ha ancora capienza per sommare Accelera e non dare il giro oltre 255
      if ( (PWM2 + Accelera) > 255   ) {
        // da il giro, satura a 255
        PWM2 = 255;
      }
      else {
        //non da il giro, si somma
        PWM2 = PWM2 + Accelera;
      }

    }
    else {
      //siamo nella direzione sbagliata
      // controlla se PWM puo ancora essere decrementato di Accelera e non dare il giro sotto lo 0
      if ( (PWM2 - Accelera) <  1  ) {
        // da il giro, si satura a 0 e si inverte la direzione
        PWM2 = 0;
        Serial.println(F( "!!! PWM2 = 0"));
        DIREZIONE2 = true;
      }
      else {
        // non da il giro, si sottrae
        PWM2 = PWM2 - Accelera;
      }


    } // DIREZIONE1 == false

  } //)MOTORON)


}

//xxxxxxxxxxxxxxxxxxxxxxxxxxxxxxxxxxxxxxxxxxxxxxxxxxxxxxxxxxxxx
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

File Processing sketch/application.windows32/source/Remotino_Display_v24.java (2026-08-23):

import processing.core.*; 
import processing.data.*; 
import processing.event.*; 
import processing.opengl.*; 

import processing.serial.*; 
import static javax.swing.JOptionPane.*; 

import java.util.HashMap; 
import java.util.ArrayList; 
import java.io.File; 
import java.io.BufferedReader; 
import java.io.PrintWriter; 
import java.io.InputStream; 
import java.io.OutputStream; 
import java.io.IOException; 

public class Remotino_Display_v24 extends PApplet {




Serial myPort;  
String StringFromSerialLine;     
String OldStringFromSerialLine;  
String ExtractStr;   
int ExtractVal;    
int LenSFSL; 

final boolean debug = true;

Gauge Power1, Power2;
int Power1_val = 0;
int Power2_val = 0;

// === VARIABILI PER MANTENERE LO STATO DELLE FRECCE ===
int dir1_val = -1; // -1 = spento/iniziale, 0 = indietro (giallo), 1 = avanti (blu)
int dir2_val = -1;

// === VARIABILI PER MANTENERE LO STATO DEGLI INDICATORI ===
int motn_val = 0;
int smod_val = 0;

// === ARRAY STATO INDIPENDENTE PER I 4 SCAMBI ===
// Ogni indice gestisce uno scambio (-1 = base, 1 = img1, 2 = img2)
int[] statoScambi = {-1, -1, -1, -1};

// === GESTIONE BOOST INDIPENDENTI ===
int boost1_val = 0; // 0 = Nero, 1 = Giallo
int boost2_val = 0; // 0 = Nero, 1 = Giallo

PImage img, img1, img2;

public void setup(){
  
  Power1 = new Gauge(250, 0, 255, 25, "Power1"); 
  Power2 = new Gauge(250, 0, 255, 25, "Power2"); 

  String COMx, COMlist = "";

  try {
    if(debug) printArray(Serial.list());
    int i = Serial.list().length;
    if (i != 0) {
      if (i >= 2) {
        for (int j = 0; j < i;) {
          COMlist += PApplet.parseChar(j+'a') + " = " + Serial.list()[j];
          if (++j < i) COMlist += ", ";
        }
        COMx = showInputDialog("Which COM port is correct? (a,b,..):\n"+COMlist);
        if (COMx == null) exit();
        if (COMx.isEmpty()) exit();
        i = PApplet.parseInt(COMx.toLowerCase().charAt(0) - 'a') + 1;
      }
      String portName = Serial.list()[i-1];
      if(debug) println(portName);
      myPort = new Serial(this, portName, 115200);
      myPort.bufferUntil('\n'); 
    }
    else {
      showMessageDialog(frame,"Device is not connected to the PC");
      exit();
    }
  }
  catch (Exception e)
  {
    showMessageDialog(frame,"COM port is not available (may be in use by another program)");
    println("Error:", e);
    exit();
  }  

  img = loadImage( "scambio0.jpg" );
  img1 = loadImage( "scambioA.jpg" );
  img2 = loadImage( "scambioB.jpg" );
}

public void draw(){
  // Pulisce lo schermo ad ogni ciclo
  background(200); 

  // --- 1. RICEZIONE E DECODIFICA SERIALE ---
  if (myPort != null && myPort.available() > 0) { 
     StringFromSerialLine = myPort.readStringUntil('\n'); 
  } 

  if (StringFromSerialLine != null) {
    String cleanLine = StringFromSerialLine.trim();

    if (!cleanLine.equals(OldStringFromSerialLine)) {
        println("Ricevuto: " + cleanLine); 
        OldStringFromSerialLine = cleanLine; 

        if (cleanLine.length() >= 5) {
           ExtractStr = cleanLine.substring(0, 4);

           switch(ExtractStr) {

             case "PWM1": 
               ExtractVal = Integer.parseInt(cleanLine.substring(5).trim()); 
               Power1_val = ExtractVal;                
             break;

             case "PWM2": 
               ExtractVal = Integer.parseInt(cleanLine.substring(5).trim()); 
               Power2_val = ExtractVal;                
             break;

             case "MOTN":  
               motn_val = Integer.parseInt(cleanLine.substring(5).trim()); 
             break;

             case "SMOD": 
               smod_val = Integer.parseInt(cleanLine.substring(5).trim()); 
             break;

             case "RLON":
               int rlon_val = Integer.parseInt(cleanLine.substring(5).trim());
               // Aggiorna solo lo scambio interessato mantenendo gli altri intatti
               if (rlon_val == 0) statoScambi[0] = 1; // Scambio 2-1
               if (rlon_val == 1) statoScambi[0] = 2;
               if (rlon_val == 2) statoScambi[1] = 1; // Scambio 4-3
               if (rlon_val == 3) statoScambi[1] = 2;
               if (rlon_val == 4) statoScambi[2] = 1; // Scambio 6-5
               if (rlon_val == 5) statoScambi[2] = 2;
               if (rlon_val == 6) statoScambi[3] = 1; // Scambio 8-7
               if (rlon_val == 7) statoScambi[3] = 2;
             break;

             case "DIR1": 
               dir1_val = Integer.parseInt(cleanLine.substring(5).trim()); 
             break;

             case "DIR2": 
               dir2_val = Integer.parseInt(cleanLine.substring(5).trim()); 
             break;

           }   // switch
         } 
       } 
  } 

  // --- CONTROLLO ACCENSIONE BOOST 1 E BOOST 2 ---
  boost1_val = (Power1_val >= 250) ? 1 : 0;
  boost2_val = (Power2_val >= 250) ? 1 : 0;

  // --- 2. DISEGNO CORNICI NERE DI CONTORNO (3px) ---
  stroke(0);          // Colore Nero
  strokeWeight(3);    // Spessore 3 pixel
  noFill();           // Solo bordo trasparente

  // Cornice 1: Contorna la colonna degli scambi a sinistra
  rect(10, 15, 230, 560);

  // Cornice 2: Contorna il blocco dei Gauge, Boost, Linee, Motor e Join a destra
  rect(255, 5, 520, 410);

  // --- 3. RENDERING GRAFICO DELL'INTERFACCIA ---

  textAlign(CENTER, CENTER);

  // --- SPIE MOTOR E 1-2 JOIN ---
  
  // SPIA MOTOR (Sotto Power2, asse X = 395)
  if (motn_val == 0) fill(50, 50, 50); // Grigio OFF
  else fill(0, 255, 0);                 // Verde ON
  stroke(255);
  strokeWeight(1);
  ellipse(395, 330, 45, 45);  
  textSize(16);
  fill(0, 0, 0);
  text("MOTOR ON", 395, 370);

  // SPIA 1-2 JOIN (Sotto Power1, asse X = 655)
  if (smod_val == 0) fill(50, 50, 50); // Grigio OFF
  else fill(255, 0, 0);                 // Rosso ON
  stroke(255);
  strokeWeight(1);
  ellipse(655, 330, 45, 45);  
  textSize(16);
  fill(0, 0, 0);
  text("1-2 JOIN", 655, 370);

  // --- COLONNA UNICA SCAMBI (PARTE SINISTRA) ---
  int scaX = 20;      // Inizio immagine
  int scaTextX = 100; // Centro orizzontale immagine per testo
  
  int y1 = 30;
  int y2 = 170;
  int y3 = 310;
  int y4 = 450;

  // 1. Immagini Scambio Base
  image(img, scaX, y1);
  image(img, scaX, y2);
  image(img, scaX, y3);
  image(img, scaX, y4);

  // 2. DISEGNO STATI SCAMBI IN BASE ALL'ARRAY
  if (statoScambi[0] == 1) image(img1, scaX, y1);
  if (statoScambi[0] == 2) image(img2, scaX, y1);

  if (statoScambi[1] == 1) image(img1, scaX, y2);
  if (statoScambi[1] == 2) image(img2, scaX, y2);

  if (statoScambi[2] == 1) image(img1, scaX, y3);
  if (statoScambi[2] == 2) image(img2, scaX, y3);

  if (statoScambi[3] == 1) image(img1, scaX, y4);
  if (statoScambi[3] == 2) image(img2, scaX, y4);
  
  // 3. Testi Scambi
  fill(0);
  textSize(13);
  text("SCAMBIO 1-2", scaTextX, y1 + 100); 
  text("SCAMBIO 3-4", scaTextX, y2 + 100);  
  text("SCAMBIO 5-6", scaTextX, y3 + 100); 
  text("SCAMBIO 7-8", scaTextX, y4 + 100);
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

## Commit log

2026-08-23 Update README with video and image references
    Added video link and image for relay board in README.
2026-08-23 Enhance Readme with project details and BOOST function
    Updated the general schema section to clarify project replication and added a new section for the BOOST button functionality.
2026-08-23 Update Readme with BOOST function and new sections
    Added information about open source sources and prototype image.
2026-08-23 Clarify track switching and join mode instructions
    Updated the explanation for switching tracks and clarified the use of the join mode.
2026-08-23 Clarify binary switch function in Readme
    Updated the description of the binary switch function to clarify the process of switching between tracks.
2026-08-23 Expand Readme with project details and instructions
    Added detailed descriptions of the Remotino Nano Dual Rail project, including features, system architecture, relay configuration, and instructions for building and debugging.
2026-08-23 Add README for Remotino Nano Dual Rail project
    Added detailed project documentation for Remotino Nano Dual Rail, including features, system architecture, relay configuration, and instructions for building the project.
2026-08-23 Fix formatting in README for PWM control description
2026-08-25 add kicad folder
    add kicad folder
    [Remotino Nano2.kicad_pcb, Remotino Nano2.kicad_sch]
2026-08-27 Enhance README with links and circuit explanation
    Updated README with additional links and clarified text regarding circuit connections.
2026-08-31 aggiunto potenziometri
    aggiunto potenz.
    [Remotino Nano2.kicad_sch]
